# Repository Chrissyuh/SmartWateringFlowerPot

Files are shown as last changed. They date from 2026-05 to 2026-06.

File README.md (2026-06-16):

# Self-Watering Flower Pot V2

Custom ESP32-S3 controller hardware and bring-up firmware for a self-watering flower pot prototype.

This repository contains the KiCad design files, generated fabrication outputs, mechanical STEP exports, board renders, BOM notes, bring-up reports, and the first safe test firmware used on the assembled Board A prototype.

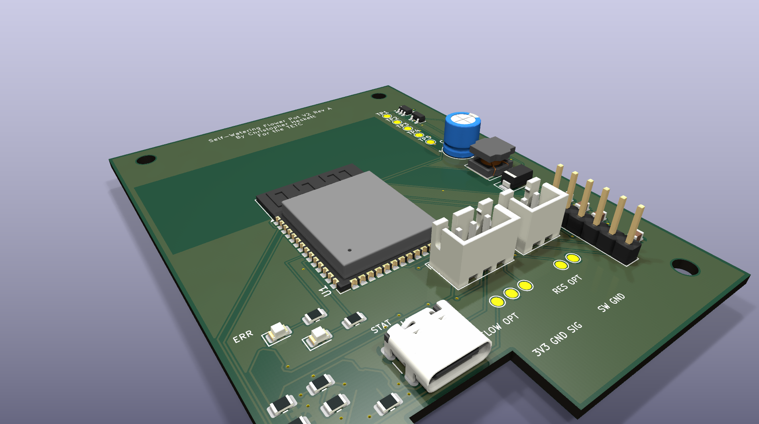
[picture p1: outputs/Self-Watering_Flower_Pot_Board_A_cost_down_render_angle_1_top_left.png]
Board A render


## Current Status

- Board A cost-down prototype has been fabricated and hand assembled for bring-up.
- USB-C power, 3.3 V regulator, ESP32-S3 native USB flashing, status LEDs, moisture ADC, and pump-gate bring-up checks have been tested.
- Current firmware is a supervised pump-test build with adjustable manual pump pulses and a hard 2 second firmware maximum.
- Board B UI daughterboard files remain in the repository as a deferred optional design.
- The cost-down Board A fabrication package is available in `fabrication/board_a_cost_down/`.

## Hardware Overview

Board A is the main controller board:

- ESP32-S3-WROOM-1-N8 module
- USB-C 5 V input
- AP63203 buck regulator for the 3.3 V logic rail
- Capacitive soil moisture sensor input on `J3`
- AO3400A low-side pump MOSFET footprint with gate resistor and pulldown
- SS34-style pump flyback diode
- Red error LED and green status LED
- Optional reservoir switch and flow pulse pads
- Debug/programming backup header `J7`
- Test points for rails and key signals

Board B is a deferred UI daughterboard concept with OLED/encoder support.

## Firmware

The current bring-up firmware lives in `firmware/testcode1/`.

It hosts a local Wi-Fi access point and web page:

- SSID: `FlowerPot-testcode1`
- Password: `flowerpot1`
- URL: `http://192.168.4.1`

The page shows moisture ADC readings, rolling average, min/max/span, rough wetness band, collapsible charts, deep ESP diagnostics, optional input short status, flow pulse count, AP-client/session counters, Wi-Fi settings, LED test buttons, session JSON export, diagnostics JSON export, and a supervised adjustable pump test button. The firmware also prints USB serial UI hints so the Windows helper in `firmware/testcode1/tools/` can open the best available UI URL from a data-cable connection.

Important safety rule: this is not autonomous watering firmware. The pump button requires a browser warning acknowledgement, and the firmware caps each pump run at 2000 ms.

## Repository Map

- `SmartWateringFlowerPot.kicad_pro`, `.kicad_sch`, `.kicad_pcb` - Board A KiCad project
- `board_b_ui/` - deferred UI board KiCad project
- `firmware/testcode1/` - PlatformIO bring-up firmware
- `docs/` - design notes, pinout, BOM notes, bring-up checklist, and hardening review
- `reports/` - saved ERC/DRC and audit reports
- `outputs/` - schematic PDFs, routing PDFs/SVGs, reference images, and 3D renders
- `fabrication/` - Gerbers, drill files, BOM CSVs, and fab zips
- `mechanical/` - STEP exports for enclosure/mechanical fit checks
- `CODEX_HANDOVER.md` - detailed project history and design context

## Bring-Up Notes

Before connecting a pump:

- Verify `+5V`, `+3V3`, and `GND`.
- Confirm there are no rail shorts.
- Confirm the ESP32 flashes over USB.
- Confirm `PUMP_GATE` remains LOW during boot/reset.
- Test the MOSFET gate with the pump disconnected.
- Use short, supervised pump tests only after the MOSFET and flyback diode are verified. Do not run the pump from a laptop USB port.

The moisture connector `J3` board order is:

```text
3V3  GND  SIG
```

The common capacitive sensor mapping is:

```text
VCC -> +3V3
GND -> GND
AOUT -> SIG
```

## Build Firmware

From `firmware/testcode1/`:

```powershell
python -m platformio run
python -m platformio run --target upload
```

The current `platformio.ini` targets the ESP32-S3 over `COM3`; change the port if your machine enumerates it differently.

## KiCad Checks

KiCad 9 is expected. If `kicad-cli` is on your PATH:

```powershell
kicad-cli sch erc --format report --output reports/erc.txt SmartWateringFlowerPot.kicad_sch
kicad-cli pcb drc --format report --output reports/drc.txt SmartWateringFlowerPot.kicad_pcb
```

KiCad GUI remains the source of truth for visual PCB edits.

## License

This project is released under the MIT License. See `LICENSE`.

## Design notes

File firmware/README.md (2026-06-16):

# Firmware

Firmware for the self-watering flower pot controller.

## Current Firmware

The active bring-up firmware is `testcode1/`.

It is a controlled pump-test build:

- Starts `GPIO4 / PUMP_GATE` LOW at boot.
- Allows a web UI pump pulse only after a first-use browser warning.
- Caps pump runtime in firmware at `2000 ms`.
- Hosts a local AP at all times.
- Can optionally join home Wi-Fi from the settings form while keeping the AP online.
- Prints USB serial UI hints so a Windows helper can open the web UI from a data-cable connection.
- Reads the moisture ADC continuously.
- Tracks moisture raw, rolling average, min/max/span, and rough diagnostic band.
- Records a rolling moisture/client history buffer and exposes collapsible charts in the hosted page.
- Downloads a session JSON export with firmware identity, moisture stats/history, AP-client counters, LED-test counters, flow pulses, and pump-run count.
- Exposes a deep diagnostics panel/API for reset reasons, boot count, pump-interrupted reset clues, heap/flash/sketch state, chip temperature, GPIO state, and loop health.
- Shows live optional input short status for `TP6-TP7` and `TP10-TP9`.
- Provides LED test buttons for the red and green board LEDs.

## Build

From `firmware/testcode1/`:

```powershell
python -m platformio run
python -m platformio run --target upload
```

The current configuration uses `COM3`; update `platformio.ini` if the ESP32-S3 appears on another port.

To open the UI from Windows over the USB serial discovery path:

```powershell
cd firmware\testcode1
.\tools\open-flowerpot-ui.ps1
```

For a simple plug-in watcher:

```powershell
cd firmware\testcode1
.\tools\watch-flowerpot-ui.ps1
```

This does not turn USB into Ethernet and does not switch Wi-Fi networks. It opens the ESP32's home-Wi-Fi URL when available, otherwise the AP URL.

## Pump Safety Direction

The current firmware is still only for supervised testing. Future autonomous pump firmware should add watering control only after hardware bring-up proves:

- MOSFET orientation is correct.
- `PUMP_GATE` is LOW during boot/reset.
- Flyback diode orientation is correct.
- Pump current is measured.
- A hard maximum runtime is enforced.
- Manual pump tests are short and explicit.

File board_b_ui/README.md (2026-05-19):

# Board B UI Daughterboard

Board B connects to Board A J6 through J1 with the same pin order:

1. `+3V3`
2. `GND`
3. `SDA`
4. `SCL`
5. `ENC_A`
6. `ENC_B`
7. `ENC_SW`
8. `ERROR_LED`
9. `STATUS_LED`

The OLED header target is the common 4-pin SSD1306 I2C module order `GND`, `VCC/3V3`, `SCL`, `SDA`. Verify the actual module pin order before fabrication.

The PCB outline is 64 mm x 38 mm with M2.5 non-plated mounting holes. The front side is the user-facing panel with the OLED header/module outline, EC11 encoder footprint, error/status LEDs, and labels. The 9-pin JST-XH cable connector and the support R/C parts are on the back side.

Board B has explicit routed copper for every net plus front/back `GND` zones. Refill zones in KiCad with `B` after manual edits and rerun DRC before fabrication.

Current review/fabrication artifacts:

- Checks: `reports/erc-board-b-front-panel.txt`, `reports/drc-board-b-front-panel.txt`, and `reports/drc-board-b-front-panel-parity.txt`
- Routing review: `outputs/BoardB_UI_routing.svg` and `outputs/BoardB_UI_routing.pdf`
- Schematic PDF: `outputs/BoardB_UI_schematic.pdf`
- STEP: `mechanical/BoardB_UI.step`
- Gerbers and drills: `../fabrication/board_b/`

The KiCad footprint references an EC11 3D model under `Rotary_Encoder.3dshapes`. This KiCad install does not include that model, so the STEP export may omit the encoder body even though the footprint, holes, and courtyard are present.

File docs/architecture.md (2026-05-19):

# Self-Watering Flower Pot V2 Architecture

## Rev A Goal

Rev A is a reliable embedded/mechatronics prototype for a self-watering flower pot. It uses an ESP32-S3 module, a custom PCB, clean connectorized wiring, a protected low-side pump driver, calibrated moisture sensing, a local OLED/encoder UI, and clear fault signaling.

The first build uses a hybrid workflow: Codex prepares documentation, checks, reports, and exports; KiCad GUI remains the source of truth for schematic placement, PCB placement, routing, board outline, and enclosure-sensitive mechanical decisions.

## Power Tree

```text
5V USB-C input
  |
  +-- Pump + bulk input capacitance
  |
  +-- AP63203WU-7 buck regulator
        |
        +-- +3V3 logic rail
              +-- ESP32-S3-WROOM-1-N8
              +-- Moisture sensor power/reference
              +-- OLED / UI logic
              +-- Pullups, LEDs, sensor inputs
```

Design rules:
- USB-C is a 5V sink only for Rev A; do not add USB-PD complexity.
- Add USB-C CC resistors if using a bare USB-C receptacle.
- Keep the buck regulator layout compact and close to its input/output capacitors and inductor.
- Keep pump current loops short and away from moisture ADC routing.
- Include test pads for `+5V`, `+3V3`, and `GND`.

## Functional Blocks

### MCU

Use `ESP32-S3-WROOM-1-N8` as the main controller. Place the module with the antenna at a board edge and respect the keepout. Preserve native USB if practical and include backup UART/debug pads.

### Pump Driver

Use a low-side N-MOSFET switch:

```text
+5V -> PUMP+ connector
PUMP- connector -> MOSFET drain
MOSFET source -> GND
ESP32 GPIO -> gate resistor -> MOSFET gate
MOSFET gate -> pulldown -> GND
Flyback diode across pump, reverse-biased during normal operation
```

Required support:
- AO3400A or equivalent logic-level N-MOSFET.
- 100 ohm to 330 ohm gate resistor.
- 100k gate pulldown.
- SS34 or similar flyback diode.
- Pump connector polarity labels.
- Test pad for `PUMP_GATE`.

### Sensors

The capacitive moisture sensor uses a 3-pin connector: `+3V3`, `GND`, `MOISTURE_ADC`. The ADC signal should use an ESP32-S3 ADC1-capable GPIO and may include a small RC low-pass filter plus a series resistor.

The reservoir switch is included as a 2-pin connector with a pullup or pulldown chosen during schematic capture. Firmware must treat an empty or missing reservoir as a pump lockout.

The flow sensor connector is optional-ready. If populated, `FLOW_PULSE` must be 3.3V-safe before reaching the ESP32.

### User Interface

The UI consists of an SSD1306 I2C OLED, EC11 rotary encoder with push switch, and red error LED. It may live on the main board or a cabled/daughter UI board depending on enclosure fit.

Use I2C pullups to `+3V3`, not `+5V`.

## First-Version KiCad Workflow

1. Build project structure and documentation.
2. Plan schematic sheets, connector pinouts, and ESP32 pins.
3. Place schematic manually in KiCad GUI.
4. Run ERC and save the report in `reports`.
5. Assign and verify footprints.
6. Place PCB manually in KiCad GUI with power, antenna, connector, and enclosure constraints first.
7. Route PCB manually in KiCad GUI.
8. Run DRC and save the report in `reports`.
9. Export fabrication outputs only after ERC/DRC results are acceptable.

## Open Mechanical Decisions

- Main board only vs. main board plus UI daughterboard.
- USB-C location relative to enclosure wall.
- OLED and encoder front-panel location.
- Mounting hole positions and screw/inset hardware.
- Pump and sensor connector access direction.

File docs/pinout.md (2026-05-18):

# ESP32-S3 Pin Allocation Draft

This is a Rev-A planning table for `ESP32-S3-WROOM-1-N8`. Confirm every selected pin against the exact module datasheet, KiCad symbol, and boot-strapping notes before routing.

Avoid using ESP32 pins that conflict with boot mode, flash/PSRAM, native USB, or module-reserved functions unless the schematic intentionally handles those constraints.

## Draft GPIO Allocation

| Signal | Draft GPIO | Direction | Electrical notes | Firmware notes |
|---|---:|---|---|---|
| `MOISTURE_ADC` | GPIO1 | Input analog | ADC1-capable, 3.3V max, optional RC filter | Average/filter and calibrate dry/wet values |
| `PUMP_GATE` | GPIO4 | Output | Gate resistor plus 100k pulldown required | Default LOW at boot; enforce max runtime |
| `I2C_SDA` | GPIO8 | I/O | Pull up to `+3V3` only | OLED and optional I2C devices |
| `I2C_SCL` | GPIO9 | Output | Pull up to `+3V3` only | OLED and optional I2C devices |
| `ENC_A` | GPIO10 | Input | Pullup and/or debounce | Rotary encoder channel A |
| `ENC_B` | GPIO11 | Input | Pullup and/or debounce | Rotary encoder channel B |
| `ENC_SW` | GPIO12 | Input | Pullup and debounce | Encoder push button |
| `RESERVOIR_SW` | GPIO13 | Input | Pullup/pulldown per switch wiring | Block pump when reservoir is empty |
| `FLOW_PULSE` | GPIO14 | Input | Must be 3.3V-safe; level shift if sensor is 5V | Interrupt-capable pulse count |
| `ERROR_LED` | GPIO15 | Output | LED resistor to suit chosen wiring | Active fault indication |
| `STATUS_LED` | GPIO16 | Output | Optional LED resistor | Heartbeat/status indication |
| `UART_TXD` | GPIO17 | Output | Test pad/header optional | Backup debug/programming |
| `UART_RXD` | GPIO18 | Input | Test pad/header optional | Backup debug/programming |

## Reserved / Special Signals

| Signal | Notes |
|---|---|
| `USB_D+` / `USB_D-` | Preserve native USB pins if used for programming/debug. Route as a controlled, short differential pair when practical. |
| `EN` | Include reset circuit and test pad. |
| `BOOT` / `IO0` | Include boot button or accessible test pad if needed by final programming flow. |
| `+3V3` | Logic rail for ESP32, OLED logic, pullups, and sensors that are 3.3V compatible. |
| `+5V` | Pump rail and USB input rail. Do not feed directly into ESP32 GPIO. |

## Connector Pinout Drafts

### J1 USB-C Power Input

| Pin group | Net |
|---|---|
| VBUS | `+5V` |
| GND | `GND` |
| CC1/CC2 | Sink resistors per USB-C receptacle design |
| D+/D- | Native USB if used; otherwise document no-connect intentionally |

### J2 Pump

| Pin | Net | Notes |
|---:|---|---|
| 1 | `PUMP_PLUS` / `+5V` | Label `PUMP+` |
| 2 | `PUMP_LOW` | To MOSFET drain; label `PUMP-` |

### J3 Moisture Sensor

| Pin | Net | Notes |
|---:|---|---|
| 1 | `+3V3` | Sensor power if sensor is 3.3V compatible |
| 2 | `GND` | Sensor ground |
| 3 | `MOISTURE_ADC` | ADC1 input, 3.3V max |

### J4 Reservoir Switch

| Pin | Net | Notes |
|---:|---|---|
| 1 | `RESERVOIR_SW` | Pullup or pulldown in schematic |
| 2 | `GND` or `+3V3` | Choose to match switch wiring |

Default: wire switch to `GND` and use a pullup to `+3V3`, unless the selected float switch requires otherwise.

### J5 Optional Flow Sensor

| Pin | Net | Notes |
|---:|---|---|
| 1 | `+3V3` or `+5V` | Match selected sensor |
| 2 | `GND` | Sensor ground |
| 3 | `FLOW_PULSE` | Must be level-shifted or divided if sensor output is 5V |

### J6 UI Connector

| Pin | Net | Notes |
|---:|---|---|
| 1 | `+3V3` | UI logic power |
| 2 | `GND` | UI ground |
| 3 | `I2C_SDA` | OLED data |
| 4 | `I2C_SCL` | OLED clock |
| 5 | `ENC_A` | Encoder A |
| 6 | `ENC_B` | Encoder B |
| 7 | `ENC_SW` | Encoder push |
| 8 | `ERROR_LED` | Front-panel fault LED |
| 9 | `STATUS_LED` | Optional status LED or spare GPIO |

## Must-Verify Before Routing

- Confirm the exact ESP32-S3 symbol pin numbers and module-reserved pins.
- Confirm `PUMP_GATE` does not toggle or float high during reset/boot.
- Confirm moisture ADC uses ADC1, not ADC2.
- Confirm I2C pullups are to `+3V3`.
- Confirm all external inputs are 3.3V-safe.
- Confirm every connector pin order matches the real cable/module orientation.

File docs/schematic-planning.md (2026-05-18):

# Schematic Planning Checklist

Do not begin PCB routing until this checklist is reviewed against the schematic.

## Suggested Sheets Or Sections

1. `Power_Input_Regulation`
2. `MCU_ESP32`
3. `Pump_Driver`
4. `Sensors_Connectors`
5. `User_Interface`
6. `Debug_Testpoints`

For a small first schematic, these may be sections on one sheet instead of separate hierarchical sheets.

## Support Components By Block

### Power Input And Regulation

- USB-C 5V input.
- CC resistors for USB-C sink behavior.
- Optional fuse/polyfuse.
- Bulk capacitance near pump/input.
- AP63203WU-7 buck regulator circuit from datasheet.
- `+5V`, `+3V3`, and `GND` test pads.

### ESP32-S3

- ESP32-S3-WROOM-1-N8 module.
- EN/reset circuit.
- BOOT/IO0 access if required.
- Native USB D+/D- if used.
- UART TX/RX test pads or header.
- Decoupling per module guidance.
- Antenna keepout note.

### Pump Driver

- Pump JST connector.
- AO3400A low-side MOSFET.
- Gate resistor.
- 100k gate pulldown.
- SS34 flyback diode.
- `PUMP_GATE` test pad.
- Clear polarity labels.

### Sensors

- Moisture sensor connector with `+3V3`, `GND`, `MOISTURE_ADC`.
- ADC series resistor and optional RC filter.
- Reservoir switch connector with defined pullup/pulldown.
- Optional flow connector with level shifting if pulse output is 5V.

### User Interface

- OLED I2C header or connector.
- I2C pullups to `+3V3`.
- EC11 encoder.
- Encoder push input.
- Red error LED and resistor.
- Optional status LED.
- UI connector if using a daughterboard.

## ERC Risks To Watch

- Missing power input source flags on `+5V` or `+3V3`.
- Hidden unconnected pins on connectors or modules.
- GPIO connected to 5V signals.
- I2C pullups tied to `+5V`.
- Missing gate pulldown on pump MOSFET.
- Flyback diode reversed or connected to wrong nets.
- Moisture signal on non-ADC or ADC2-only pin.
- Power pins hidden by symbol behavior.
- Ambiguous connector pin order.

## Manual KiCad GUI Placement Order

1. Place power input and regulator first.
2. Place ESP32 module and support parts.
3. Place pump driver and pump connector.
4. Place moisture, reservoir, and optional flow connectors.
5. Place OLED/encoder/UI connector.
6. Place LEDs and test points.
7. Assign footprints and verify every real-world connector footprint.
8. Run ERC before moving to PCB layout.

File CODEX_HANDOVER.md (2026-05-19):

# Self-Watering Flower Pot V2 — Codex + KiCad Handover

## Purpose of this file

This file is the main handover document for Codex while working inside the KiCad project folder for the Self-Watering Flower Pot V2.

Codex should treat this as project context, design intent, safety rules, and a task guide. KiCad GUI remains the source of truth for visual schematic/PCB work. Codex should mostly help with organization, checking, documentation, reports, symbol/footprint sanity review, small controlled edits, scripts, and manufacturing-output automation.

This project is not just a quick prototype. The goal is a product-ish engineering prototype: a custom PCB, clean wiring, serviceable enclosure, calibrated control logic, clear failure modes, and a design that could be explained to mentors, judges, or engineers.

---

## Project summary

Project name: **Self-Watering Flower Pot V2**

Core idea: An ESP32-based plant pot controller that reads a capacitive soil moisture sensor, decides when watering is needed, runs a small 5V pump through a MOSFET driver, optionally verifies water flow, displays status on a small OLED, and lets the user adjust/calibrate settings through a rotary encoder/button UI.

Primary goals:

- Create a custom KiCad PCB instead of a breadboard prototype.
- Make the wiring clean using JST connectors.
- Use a safe low-voltage pump driver with flyback protection.
- Separate noisy motor power from sensitive analog sensor readings as much as practical.
- Support calibration and reliable watering behavior in firmware.
- Design around a 3D-printed or fabricated enclosure in SolidWorks.
- Keep the design realistic for a novice KiCad user while still being serious and well-engineered.

Current status:

- Board A main-controller schematic and PCB are complete enough for manufacturer preview.
- Board B UI daughterboard schematic and PCB are complete enough for manufacturer preview.
- Both boards have current clean ERC, DRC, and schematic-parity reports.
- Fabrication packages, STEP exports, schematic PDFs, routing review outputs, and 3D review images have been generated.
- `docs/pre-order-hardening-review.md` documents the remaining real-world prototype tradeoffs: Rev A has no USB input fuse/current limiter, no USB data ESD array, and no extra local ESP32 bulk capacitor directly beside U1.
- The next major job is not more routing. It is final Gerber preview, final live BOM refresh, explicit acceptance of the Rev A protection tradeoff, and then careful bring-up after boards arrive.

---

## Overall architecture

High-level block diagram:

```text
USB-C 5V input
   |
   +--> 5V rail for pump / maybe external modules
   |
   +--> 3.3V buck regulator
            |
            +--> ESP32-S3 module
            +--> soil moisture sensor logic/reference, if sensor output is 3.3V-safe
            +--> OLED / encoder / LEDs / optional sensor logic

ESP32 ADC1 pin <--- capacitive soil moisture sensor analog output
ESP32 GPIO  ----> MOSFET gate ---> pump low-side switch
ESP32 I2C   ----> OLED display / optional I2C expansion
ESP32 GPIO  <---- rotary encoder A/B + push button
ESP32 GPIO  <---- reservoir float switch or low-water sensor
ESP32 GPIO  <---- optional flow sensor pulse output
ESP32 GPIO  ----> red error LED / status LEDs
```

Preferred Rev-A architecture:

- 5V USB-C input.
- 3.3V buck regulator for ESP32 and logic.
- ESP32-S3-WROOM-1-N8 module.
- 5V mini submersible pump or similar small DC pump.
- Low-side N-MOSFET pump driver.
- Flyback diode across pump.
- Capacitive soil moisture sensor through connector.
- 0.96 inch SSD1306 I2C OLED on a separate UI board or cable.
- EC11-style rotary encoder with push button.
- Red error LED.
- JST-XH connectors where practical.
- 0805 passives.
- Test pads and labeled connectors.

---

## Design philosophy

This should feel like a serious embedded/mechatronics product prototype, not a toy breadboard circuit.

Important priorities:

1. **Safety and robustness first**
   - Pump must not be able to run forever in normal firmware failure cases.
   - MOSFET gate needs a pulldown.
   - Pump needs flyback protection.
   - Inputs need to be 3.3V-safe for ESP32 pins.
   - Moisture readings should not be destroyed by motor noise.

2. **Serviceability**
   - Use connectors for pump, sensor, UI, reservoir sensor, and power where practical.
   - Label connectors clearly on silkscreen.
   - Include test pads for rails and key signals.
   - Make it possible to debug without guessing.

3. **Good learning workflow**
   - This is a novice KiCad project, so reminders and checklists matter.
   - Do not assume the schematic or PCB is correct because it “looks okay.”
   - Use ERC/DRC often.
   - Keep footprints, pinouts, connectors, and power rails explicit.

4. **SolidWorks integration**
   - PCB shape, connector placement, button/display locations, and mounting holes should eventually line up with the enclosure.
   - The expected workflow is:

```text
KiCad schematic + rough footprints
-> KiCad PCB rough placement
-> SolidWorks enclosure / fit check
-> KiCad PCB revision
-> SolidWorks revision
-> repeat
```

---

## Hard constraints / do-not-break rules

Codex must follow these rules unless the user explicitly says otherwise.

### KiCad file safety

- Do not blindly rewrite `.kicad_sch` or `.kicad_pcb` files.
- Before editing schematic or PCB files, explain the intended change.
- Prefer checklists, reports, Python scripts, and small controlled patches over huge direct edits.
- KiCad GUI remains the source of truth for visual PCB edits.
- Do not change footprints, net names, connector pinouts, power paths, board shape, or mounting constraints without explicit approval.
- Run ERC after schematic edits when possible.
- Run DRC after PCB edits when possible.
- Keep reports in `/reports`.
- Keep outputs in `/outputs` or `/fabrication`.

### Electronics safety

- ESP32 GPIOs are 3.3V logic. Do not feed 5V into ESP32 pins.
- Moisture sensor must use ADC1 pins when possible because ESP32 ADC2 conflicts with Wi-Fi on many ESP32 variants.
- Pump must be switched with a proper MOSFET driver, not directly from a GPIO.
- MOSFET gate must have a pulldown resistor.
- Pump must have a flyback diode or equivalent protection.
- Keep motor current path short and away from sensitive analog input traces.
- Add bulk capacitance near pump/5V input and local decoupling near ICs/modules.
- Use enough trace width for pump current.
- Include test points for 5V, 3.3V, GND, pump gate, moisture ADC, and I2C if space allows.

### Firmware behavior constraints that influence hardware

The hardware should support firmware safety features:

- Hysteresis around moisture threshold.
- Cooldown after watering.
- Maximum pump runtime or maximum mL per watering event.
- Pump lockout/fault if no water is detected.
- Optional flow pulse counting using interrupt-capable GPIO.
- Calibration stored in nonvolatile memory.
- User-visible fault state through OLED and red error LED.

---

## Preferred components / Rev-A defaults

These are the current preferred defaults, not final purchasing guarantees. Codex should use these as working assumptions unless the user provides updated part numbers.

| Function | Preferred part / style | Notes |
|---|---|---|
| MCU | ESP32-S3-WROOM-1-N8 | Module preferred over dev board for product-ish PCB. Native USB possible. |
| Main input | USB-C 5V | Use as power input. Rev-A can avoid USB-PD complexity. |
| 3.3V regulator | AP63203WU-7 buck | 5V to 3.3V logic rail. Check exact footprint and recommended layout. |
| Pump switch | AO3400A N-MOSFET | Low-side switching for small DC pump. Confirm current/thermal margin. |
| Flyback diode | SS34 or similar Schottky | Across pump/load path. Orientation matters. |
| Pump | Small 5V DC mini submersible pump | Exact pump may vary. Connector should allow replacement. |
| Soil sensor | Capacitive soil moisture sensor | Analog output. Must be 3.3V-safe before ESP32 ADC. |
| Display | 0.96 inch SSD1306 I2C OLED | Could be on UI daughterboard or cabled. |
| Encoder | EC11 rotary encoder w/ push | Main local UI control. Needs debouncing in firmware or hardware. |
| Error LED | Red LED | User-visible fault indicator. |
| Connectors | JST-XH preferred | Good for pump/sensors/power/internal wiring. |
| Passives | 0805 | Easier hand soldering than smaller packages. |
| Programming/debug | Native USB + UART header/test pads | Keep recovery/debug options. |

Potential optional components:

- Reservoir float switch connector.
- Flow sensor connector.
- Extra status LED.
- Buzzer footprint, only if useful.
- Expansion header, only if not bloating the board.
- Power switch footprint.

Avoid adding random features unless they directly support watering reliability, calibration, debugging, or enclosure usability.

---

## Board / schematic organization

The design may be one physical breakaway panel or separate PCBs. The preferred concept is a main control board plus optional breakaway UI/daughterboard sections if it reduces wiring or improves enclosure fit.

### Option A — Single main PCB only

Simpler KiCad project.

Pros:

- Less board-to-board wiring.
- Easier first PCB.
- Fewer connector mistakes.

Cons:

- OLED/button placement may be awkward.
- Enclosure front panel alignment may be harder.
- The board shape may become constrained by UI placement.

### Option B — Main board + UI daughterboard

Preferred if enclosure fit needs a front-facing display/control panel.

Main board contains:

- USB-C power input.
- 3.3V buck regulator.
- ESP32-S3 module.
- Pump MOSFET driver.
- Sensor connectors.
- Reservoir/flow connectors.
- Programming/debug headers or test pads.
- Main power/status LEDs.

UI board contains:

- OLED footprint/header.
- Rotary encoder.
- User button if separate from encoder push.
- Red error LED if front-facing.
- Board-to-board or cable connector back to main board.

Potential UI board connector signals:

```text
3V3
GND
SDA
SCL
ENC_A
ENC_B
ENC_SW
ERROR_LED or STATUS_LED
optional spare GPIO
```

### Option C — Main board + UI board + sensor/environment board

Only use if there is a real mechanical reason. More boards means more complexity, more connector pinouts, and more chances for mistakes.

---

## Suggested schematic sheets

A clean schematic structure matters. Suggested sheets:

1. `Power_Input_Regulation`
2. `MCU_ESP32`
3. `Pump_Driver`
4. `Sensors_Connectors`
5. `User_Interface`
6. `Debug_Testpoints`

If the project stays small, these can also be sections on one schematic page. The important part is readability and intentional net naming.

---

## Schematic block details

### 1. Power input and regulation

Purpose:

- Accept 5V input through USB-C.
- Generate stable 3.3V rail for ESP32 and logic.
- Provide enough bulk capacitance for pump startup transients.

Likely footprints/items:

- USB-C receptacle, USB2/power-only style if possible.
- CC resistors for USB-C sink behavior if using bare USB-C connector.
- Input fuse/polyfuse optional but useful.
- Reverse-polarity protection optional depending on input style.
- AP63203WU-7 buck regulator and required inductor/capacitors/resistors.
- 5V test pad.
- 3.3V test pad.
- Power LED optional.
- Bulk electrolytic/tantalum/polymer capacitor near 5V pump/input.
- 0.1 uF decoupling capacitors near logic IC/module pins as needed.

KiCad reminders:

- Use the exact regulator datasheet recommended footprint and layout.
- Switching regulator layout matters: keep input cap, diode/switching node/inductor feedback loop compact per datasheet.
- Keep noisy switch node copper small.
- Use a ground pour, but do not assume the pour fixes bad placement.
- Label rails clearly: `+5V`, `+3V3`, `GND`.

### 2. ESP32-S3 module

Purpose:

- Main controller.
- Reads moisture sensor.
- Controls pump MOSFET.
- Drives OLED over I2C.
- Reads encoder/buttons/sensors.
- Handles calibration and fault logic.

Likely footprints/items:

- ESP32-S3-WROOM-1-N8 module footprint.
- EN/reset circuit.
- Boot/IO0 button or programming support if needed.
- Native USB D+/D- routing if used.
- UART header/test pads as backup.
- Decoupling capacitors.
- Keepout under antenna.
- Mounting/placement with antenna at board edge where possible.

Important pin planning:

- Moisture sensor should use ADC1-capable pin.
- Flow sensor, if used, should use interrupt-capable GPIO.
- I2C needs SDA/SCL pins with pullups to 3.3V.
- Pump gate control GPIO should be safe at boot and should not accidentally turn pump on during reset.
- Encoder pins should be convenient for firmware interrupt/polling.
- Avoid strapping pins for outputs that may affect boot behavior unless intentionally designed.

Codex task:

- Help create a pin allocation table before routing.
- Check that selected pins do not conflict with bootstrapping, USB, flash, or ADC limitations.

### 3. Pump driver

Purpose:

- Switch the 5V pump safely using ESP32 logic.
- Protect against inductive kick.
- Avoid accidental pump activation at boot.

Likely footprints/items:

- Pump JST-XH connector: `PUMP+`, `PUMP-`.
- AO3400A N-MOSFET or equivalent logic-level N-MOSFET.
- Gate resistor, maybe ~100 ohm to 330 ohm.
- Gate pulldown, likely ~100k to GND.
- Flyback diode across pump, such as SS34.
- Optional TVS or snubber if noise is bad.
- Optional pump status LED, only if useful.
- Pump current path with suitable trace width.

Expected electrical topology:

```text
+5V -> Pump+ connector pin
Pump- connector pin -> MOSFET drain
MOSFET source -> GND
ESP32 GPIO -> gate resistor -> MOSFET gate
MOSFET gate -> pulldown -> GND
Flyback diode across pump, reverse-biased during normal operation
```

Safety reminders:

- The GPIO must not directly power the pump.
- The pump connector should be clearly labeled for polarity.
- The flyback diode orientation must be checked carefully.
- The MOSFET footprint pin order must be verified against the actual part and KiCad footprint.

### 4. Soil moisture sensor

Purpose:

- Read soil moisture through an analog voltage.
- Allow calibration in firmware.
- Keep analog signal reasonably clean.

Likely footprints/items:

- JST-XH or JST-PH connector for sensor.
- Pins likely: `3V3`, `GND`, `MOISTURE_ADC`.
- Optional RC low-pass filter on ADC input.
- Optional series resistor into ADC pin.
- Optional ESD protection if connector exits enclosure.
- Test pad for ADC signal.

Important constraints:

- Sensor output must not exceed 3.3V at ESP32 ADC.
- Use ADC1 pin where possible.
- Keep sensor trace away from pump trace and switching regulator noise.
- Firmware should average readings and use calibration, not raw magic numbers.

### 5. Reservoir sensor / float switch

Purpose:

- Detect low water or reservoir presence.
- Prevent pump from running dry.

Likely footprints/items:

- 2-pin JST connector.
- Pullup or pulldown resistor depending on switch wiring.
- Optional RC debounce.
- GPIO input.
- Silkscreen label showing expected switch behavior if known.

Firmware behavior:

- If reservoir empty or missing, block watering.
- Display fault message and turn on error LED.

### 6. Optional flow sensor

Purpose:

- Verify that water is actually moving.
- Count pulses to estimate amount of water dispensed.

Likely footprints/items:

- 3-pin connector: `5V or 3V3`, `GND`, `FLOW_PULSE`.
- Pullup to correct voltage.
- Level shifting if sensor output is 5V.
- Optional input protection.
- Interrupt-capable ESP32 GPIO.

Constraints:

- Do not connect a 5V pulse output directly to ESP32 GPIO.
- Flow counting should be interrupt-based in firmware.
- If no pulses arrive after pump starts, enter no-flow fault.

### 7. User interface

Purpose:

- Show moisture/status/faults/settings.
- Let user calibrate dry/wet values and adjust thresholds.

Likely footprints/items:

- 0.96 inch SSD1306 I2C OLED header or direct-solder footprint.
- EC11 rotary encoder.
- Encoder push button.
- Red error LED with resistor.
- Optional status LED.
- UI board connector if separate.

Signals:

```text
3V3
GND
SDA
SCL
ENC_A
ENC_B
ENC_SW
ERROR_LED
optional spare
```

Reminders:

- I2C pullups should go to 3.3V, not 5V.
- OLED module voltage compatibility must be checked.
- Encoder needs debouncing in firmware; small RC filters are optional.
- Error LED should be visible from outside the enclosure.

### 8. Debug/test points

Purpose:

- Make first bring-up less painful.
- Make it easier to diagnose board mistakes.

Recommended test points:

- `GND`
- `+5V`
- `+3V3`
- `EN`
- `BOOT/IO0` if relevant
- `TXD`
- `RXD`
- `USB_D+`
- `USB_D-`
- `PUMP_GATE`
- `MOISTURE_ADC`
- `SDA`
- `SCL`
- `FLOW_PULSE` if used

---

## Net naming conventions

Use clear net names. Examples:

Power:

```text
+5V
+3V3
GND
VBUS
```

Pump:

```text
PUMP_GATE
PUMP_LOW
PUMP_PLUS
```

Sensors:

```text
MOISTURE_ADC
RESERVOIR_SW
FLOW_PULSE
```

I2C:

```text
I2C_SDA
I2C_SCL
```

UI:

```text
ENC_A
ENC_B
ENC_SW
ERROR_LED
STATUS_LED
```

Do not use vague net names like `SIGNAL`, `SENSOR`, `OUT`, `GPIO1`, unless they are temporary and documented.

---

## Footprint checklist

Before routing, Codex should help the user verify this list.

### Power

- USB-C connector footprint matches actual part.
- CC resistors are included if using USB-C power input directly.
- Buck regulator footprint matches exact AP63203 package.
- Inductor footprint matches actual selected inductor.
- Input/output capacitors have correct package and voltage rating.
- Test points for 5V/3.3V/GND.

### MCU

- ESP32-S3-WROOM footprint exactly matches module variant.
- Antenna keepout is present and respected.
- EN/BOOT/programming circuit is correct.
- USB data pins, if used, are routed intentionally.
- UART backup header/test pads exist.

### Pump driver

- AO3400A footprint pinout checked against datasheet.
- SS34 diode footprint checked.
- Pump connector footprint matches actual JST part.
- Gate resistor/pulldown included.
- Pump current traces sized appropriately.

### Sensors

- Moisture sensor connector pinout documented.
- Reservoir switch connector documented.
- Flow sensor connector documented if included.
- ADC protection/filtering considered.
- 5V sensor outputs are level-shifted or divided if needed.

### UI

- OLED module footprint/header matches actual module pin order.
- Encoder footprint matches actual EC11 encoder variant.
- Button footprint matches actual part.
- LED polarity clear on silkscreen.
- UI connector pinout documented on both boards if separate.

### Mechanical

- Mounting holes sized and grounded or isolated intentionally.
- Connector access matches enclosure concept.
- USB-C port location matches enclosure access.
- OLED/encoder positions match front panel if using UI board.
- Board edge clearances are reasonable.

---

## KiCad novice reminders

Codex should remind the user of these at the right times, especially before committing to PCB layout.

### Schematic reminders

- Every symbol needs the correct footprint assigned before PCB layout.
- Power symbols create global nets; use them carefully.
- ERC warnings are not automatically false. Read them.
- Add PWR_FLAG only when the warning is about KiCad not understanding a rail is powered, not to hide real problems.
- Label connector pins clearly.
- Keep pin numbers and connector order consistent with real wiring.
- Make a pinout table before routing.
- Check OLED module pin order; cheap modules may differ.

### PCB reminders

- Set board outline on `Edge.Cuts`.
- Place mounting holes early.
- Place mechanical connectors early.
- Place the ESP32 antenna near board edge with keepout respected.
- Keep pump current loop short.
- Keep moisture ADC away from pump and switching regulator noise.
- Use a ground plane/pour.
- Refill zones before final DRC.
- Use thicker traces for pump/current paths.
- Use 45-degree routing unless there is a reason not to.
- Label connectors on silkscreen.
- Add version text like `Self-Watering Flower Pot V2 Rev A` on silkscreen.
- Export a 3D model and check in SolidWorks or KiCad 3D viewer.

### Manufacturing reminders

- Run DRC before ordering.
- Check drill files.
- Check Gerbers in a Gerber viewer.
- Verify board dimensions.
- Verify connector footprints with datasheets or printed 1:1 footprint check.
- Confirm minimum trace/space and hole sizes match the PCB manufacturer.
- Do not order before checking polarity marks and connector pinouts.

---

## Firmware behavior target

The PCB should support this kind of firmware flow:

```text
Boot
  -> initialize display, sensors, pump output off
  -> read calibration/settings from NVM
  -> show status

Main loop
  -> read moisture multiple times and average/filter
  -> compare against calibrated dry/wet thresholds
  -> check reservoir state
  -> if too dry and allowed by cooldown, water plant
  -> after watering, wait/cooldown and recheck
  -> handle errors visibly
```

Watering logic requirements:

- Use hysteresis so pump does not rapidly toggle.
- Use cooldown so watering is not repeated too quickly.
- Use maximum runtime or maximum mL limit.
- If flow sensor exists, count pulses using interrupt-based logic.
- If pump is on but no flow is detected after a short grace period, stop and show fault.
- Store calibration in nonvolatile memory.

UI target:

- Show current moisture value/percentage.
- Show dry/wet calibration state.
- Show pump status.
- Show reservoir/fault status.
- Allow calibration of dry and wet readings.
- Allow threshold adjustment.
- Allow manual pump test with safety timeout.

---

## Suggested project folder structure

```text
SelfWateringFlowerPotV2/
  SelfWateringFlowerPotV2.kicad_pro
  SelfWateringFlowerPotV2.kicad_sch
  SelfWateringFlowerPotV2.kicad_pcb
  CODEX_HANDOVER.md
  AGENTS.md
  /docs
    architecture.md
    pinout.md
    bringup-checklist.md
    bom-notes.md
  /reports
    erc.txt
    drc.txt
  /outputs
  /fabrication
    gerbers/
    drill/
    bom/
    pickplace/
  /mechanical
    board-export.step
    enclosure-notes.md
  /firmware
    README.md
```

If the KiCad project already has a different name, use that project name consistently.

---

## Recommended `AGENTS.md` content

Create or update an `AGENTS.md` file in the project root with this content:

```md
# KiCad Project Rules for Codex

This is a KiCad PCB project for the Self-Watering Flower Pot V2.

Rules:
- Do not blindly rewrite .kicad_sch or .kicad_pcb files.
- Before editing schematic or PCB files, explain the intended change first.
- Prefer using kicad-cli, Python scripts, reports, and small controlled edits.
- Run ERC after schematic changes when possible.
- Run DRC after PCB changes when possible.
- Put reports in /reports.
- Put generated manufacturing/export files in /fabrication or /outputs.
- Do not change footprints, net names, connector pinouts, power paths, board shape, mounting holes, or enclosure constraints unless explicitly asked.
- If a change is risky, create a script or patch instead of directly modifying the KiCad design file.
- KiCad GUI remains the source of truth for visual PCB edits.
- Treat CODEX_HANDOVER.md as the main project context file.
```

---

## First Codex prompt to use in the Codex app

Paste this into Codex while the KiCad project folder is open:

```text
Read CODEX_HANDOVER.md and AGENTS.md first.

This is a new KiCad project for the Self-Watering Flower Pot V2. Do not edit schematic or PCB files yet.

First tasks:
1. Identify the KiCad project files in this folder.
2. Check whether kicad-cli works.
3. Create /docs, /reports, /outputs, /fabrication, and /mechanical folders if they do not exist.
4. Create docs/pinout.md with a draft pin allocation table for ESP32-S3-WROOM-1-N8 based on the handover requirements.
5. Create docs/bringup-checklist.md with a first-power-on checklist.
6. Create docs/bom-notes.md with a draft BOM category list, not final part orders.
7. Do not modify .kicad_sch or .kicad_pcb yet.
8. Summarize what you created and what decisions still need user approval.
```

---

## Second Codex prompt: schematic planning

Use this after the first prompt succeeds:

```text
Using CODEX_HANDOVER.md, propose the schematic structure for this KiCad project.

Do not edit design files yet.

Give me:
1. Recommended schematic sheets or sections.
2. Exact connector list and pinout draft.
3. Power tree.
4. ESP32 pin allocation draft.
5. Required support components for each block.
6. ERC risks to watch for.
7. A checklist of what I should place manually in KiCad GUI first.

Keep the design realistic for Rev A and do not add feature creep.
```

---

## Third Codex prompt: after schematic parts are placed

Use this once the user has started placing parts in KiCad:

```text
Inspect the KiCad schematic. Do not edit it yet.

Check for:
1. Missing footprints.
2. Missing power symbols or unclear rails.
3. ESP32 pin conflicts or bad boot strap choices.
4. Missing pump gate pulldown, gate resistor, or flyback diode.
5. Sensor outputs that may not be 3.3V-safe.
6. Missing I2C pullups.
7. Missing test points.
8. Connector pinout ambiguity.
9. ERC issues.

Run ERC using kicad-cli if possible and save the report in /reports.
Then summarize fixes in priority order.
```

---

## Fourth Codex prompt: before PCB routing

Use this after schematic is mostly done and footprints assigned:

```text
Before I start PCB routing, review the schematic and footprint assignments.

Do not edit the PCB yet.

Create a placement strategy for:
1. USB-C input.
2. Buck regulator and power path.
3. ESP32 module and antenna keepout.
4. Pump connector and MOSFET loop.
5. Moisture sensor connector and ADC trace.
6. UI connector/OLED/encoder path.
7. Mounting holes and enclosure constraints.
8. Test points.

Also create a list of high-risk footprints I should print/check at 1:1 scale before ordering.
```

---

## Fifth Codex prompt: after PCB placement/routing

Use this after layout work:

```text
Inspect the PCB layout. Do not make direct edits yet.

Check for:
1. Board outline on Edge.Cuts.
2. Mounting holes.
3. ESP32 antenna keepout.
4. Pump current trace width and loop area.
5. Buck regulator layout risks.
6. Analog moisture trace noise risks.
7. Ground pour / zone fill issues.
8. Connector silkscreen labels.
9. Polarity markings.
10. Test point access.
11. DRC errors.

Run DRC using kicad-cli if possible and save the report in /reports.
Summarize manufacturing risks and exact fixes.
```

---

## Sixth Codex prompt: fabrication export

Use this only when schematic and PCB are reviewed:

```text
Prepare fabrication outputs for review.

Before exporting, run ERC and DRC and save reports.
If there are blocking errors, stop and summarize them instead of exporting.

If checks pass or only approved warnings remain:
1. Export Gerbers to /fabrication/gerbers.
2. Export drill files to /fabrication/drill.
3. Export BOM if possible to /fabrication/bom.
4. Export position file if useful to /fabrication/pickplace.
5. Export STEP model to /mechanical/board-export.step if possible.
6. Summarize exactly what files were created.
```

---

## Bring-up checklist draft

Use this after the PCB arrives, before connecting the pump.

### Before soldering

- Inspect board for visible fab defects.
- Confirm board revision text.
- Confirm USB-C footprint orientation.
- Confirm ESP32 module orientation.
- Confirm diode polarity markings.
- Confirm MOSFET orientation.
- Confirm connector labels and pin 1 markers.

### After partial soldering: power only

- Solder power input/regulator section first if possible.
- Do not install ESP32 module until 3.3V rail is verified, if assembly order allows.
- Apply 5V current-limited power.
- Check 5V rail.
- Check 3.3V rail.
- Check regulator temperature.
- Check for shorts between 5V/GND and 3.3V/GND.

### After MCU soldering

- Verify ESP32 power pins.
- Try programming or USB detection.
- Blink status/error LED.
- Confirm boot/reset behavior.

### Sensor/UI tests

- Test OLED I2C scan.
- Test encoder rotation and button.
- Read moisture ADC in air.
- Read moisture ADC with sensor in water/damp soil only if sensor supports it.
- Test reservoir switch input.
- Test flow sensor pulses if included.

### Pump test

- Test MOSFET gate output with pump disconnected.
- Connect dummy load or LED/resistor if useful.
- Connect pump with current-limited supply.
- Run very short pump pulse.
- Verify flyback diode orientation and MOSFET temperature.
- Verify pump cannot turn on during reset/boot.

---

## Open decisions to resolve

Codex should help track these decisions rather than assuming them.

1. Exact KiCad project name.
2. Exact USB-C connector part.
3. Exact pump part and current draw.
4. Exact moisture sensor module pin order and voltage behavior.
5. Whether flow sensor is included on Rev A or only connector-ready.
6. Whether reservoir float switch is included on Rev A.
7. Whether OLED is direct on main board, cabled, or on UI daughterboard.
8. Whether board is one PCB, breakaway panel, or separate boards.
9. Exact enclosure layout and mounting hole positions.
10. Exact PCB manufacturer constraints.
11. Whether native USB programming is enough or UART header is required.
12. Whether battery operation is completely out of scope for Rev A.

Current likely defaults:

- Use USB-C 5V, not battery.
- Include reservoir switch connector.
- Include flow sensor connector if not too much complexity, but design should still work without installing it.
- Use main board + possible UI daughterboard if enclosure fit benefits.
- Focus on a reliable Rev A, not maximum features.

---

## Rough pricing categories

This is not a final BOM. It is for planning.

| Category | Rough expected cost range | Notes |
|---|---:|---|
| PCB fabrication | $5–$30 | Depends on size, quantity, shipping, panels. |
| ESP32-S3 module | $3–$8 | Depends source and module variant. |
| Power parts | $3–$10 | USB-C, buck, inductor, caps, protection. |
| Pump driver parts | $1–$4 | MOSFET, diode, resistors, connector. |
| OLED | $2–$8 | Module style varies. |
| Encoder/buttons/LEDs | $1–$5 | Depends quality and quantity. |
| Sensors | $2–$15 | Moisture, float, optional flow. |
| Connectors/wires | $3–$15 | JST housings, crimps, premade leads. |
| Enclosure hardware | $2–$15 | Screws, inserts, gasket, printed parts. |
| Spare/debug parts | $5–$20 | Strongly recommended. |

Likely Rev-A total: about **$30–$100**, depending on parts already owned, shipping, and whether multiple boards are ordered.

---

## What Codex should produce as receipts

Good project artifacts:

- `docs/architecture.md`
- `docs/pinout.md`
- `docs/bringup-checklist.md`
- `docs/bom-notes.md`
- ERC and DRC reports.
- PCB screenshots or exported images.
- STEP model for enclosure fitting.
- Gerber/drill outputs when ready.
- A short engineering writeup explaining design choices and safety features.
- A test log after bring-up.

Avoid:

- Random generated files with unclear purpose.
- Large direct rewrites of KiCad files.
- Feature creep.
- Hiding ERC/DRC warnings without understanding them.

---

## Human design notes

The user is strong technically but new to KiCad, so Codex should act like a careful engineering assistant:

- Catch missing details early.
- Explain risks clearly.
- Use checklists.
- Keep changes controlled.
- Assume the user will make many final choices in KiCad GUI.
- Do not water down the project. The goal is a serious embedded/mechatronics prototype.

The ideal Codex behavior is not “finish the PCB for me.” The ideal behavior is:

```text
organize -> inspect -> warn -> generate checklists -> run checks -> explain errors -> help export -> document evidence
```

---

## Immediate next step

After this file is placed in the KiCad project root, create `AGENTS.md` using the recommended content above, then open the project folder in the Codex app and run the first Codex prompt.

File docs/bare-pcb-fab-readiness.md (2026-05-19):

# Bare-PCB Fab Readiness

Date: 2026-05-19

## Status

Board A and Board B are both fab-ready for bare PCB manufacturer preview.

Board A now passes ERC, DRC, and schematic parity with 0 violations and 0 unconnected pads after the four open connections were fixed and copper zones were refilled. Board B remains clean after the front-panel placement cleanup and refreshed fabrication export.

One-large-order readiness status is tracked in `docs/one-large-order-readiness.md`. The current purchasing BOM is `fabrication/bom/order-readiness-purchasing-bom.csv`; it still needs a live stock/price refresh before parts checkout.

## Board A Fab-Ready Outputs

Current reports:

- `reports/erc-order-batch-board-a.txt`: 0 violations.
- `reports/drc-order-batch-board-a.txt`: 0 violations, 0 unconnected pads.
- `reports/drc-order-batch-board-a-parity.txt`: 0 violations, 0 unconnected pads, 0 schematic parity issues.

Fixed routing/placement items:

- `R8` pad 1 to `Net-(J4-Pin_1)` reservoir switch signal.
- `C4` pad 1 to `Net-(TP5-Pin_1)` optional moisture ADC filter node.
- `R6` pad 2 to `Net-(J6-Pin_3)` SDA pullup branch.
- `U1` pad 18 to `J6` pin 5 / `Net-(J6-Pin_5)` encoder A.

Board A bare-board output package:

- Gerbers: `fabrication/board_a/gerbers/`
- Drill files and drill maps: `fabrication/board_a/drill/`
- Fab zip: `fabrication/board_a/Self-Watering_Flower_Pot_Board_A_fab.zip`
- STEP: `mechanical/BoardA.step`
- Schematic PDF: `outputs/BoardA_schematic_order_batch.pdf`
- Routing review SVG/PDF: `outputs/BoardA_routing_order_batch.svg`, `outputs/BoardA_routing_order_batch.pdf`
- 3D review images: `outputs/BoardA_3d_top.png`, `outputs/BoardA_3d_bottom.png`

## Board B Fab-Ready Outputs

Checks:

- `board_b_ui/reports/erc-board-b-front-panel.txt`: 0 violations.
- `board_b_ui/reports/drc-board-b-front-panel.txt`: 0 violations, 0 unconnected items.
- `board_b_ui/reports/drc-board-b-front-panel-parity.txt`: 0 violations, 0 unconnected items, 0 schematic parity issues.
- `board_b_ui/reports/erc-one-large-order-board-b.txt`: 0 ERC messages, 0 errors, 0 warnings.
- `board_b_ui/reports/drc-one-large-order-board-b.txt`: 0 DRC violations, 0 unconnected items.
- `board_b_ui/reports/drc-one-large-order-board-b-parity.txt`: 0 DRC violations, 0 unconnected items.
- `board_b_ui/reports/erc-order-batch-board-b.txt`: 0 violations.
- `board_b_ui/reports/drc-order-batch-board-b.txt`: 0 violations, 0 unconnected items.
- `board_b_ui/reports/drc-order-batch-board-b-parity.txt`: 0 violations, 0 unconnected items, 0 schematic parity issues.

Bare-board output package:

- Gerbers: `fabrication/board_b/gerbers/`
- Drill files and drill maps: `fabrication/board_b/drill/`
- STEP: `board_b_ui/mechanical/BoardB_UI.step`
- Schematic PDF: `board_b_ui/outputs/BoardB_UI_schematic.pdf`
- Routing review: `board_b_ui/outputs/BoardB_UI_routing.svg`
- Routing review PDF: `board_b_ui/outputs/BoardB_UI_routing.pdf`
- Fab zip: `fabrication/board_b/Self-Watering_UI_Board_B_fab.zip`
- 3D review images: `board_b_ui/outputs/BoardB_UI_3d_top.png`, `board_b_ui/outputs/BoardB_UI_3d_bottom.png`

Known acceptable Board B warning during STEP export:

- KiCad could not find the EC11 encoder 3D model. The footprint, pads, and holes are present; the STEP may omit the encoder body.

## Order Checklist

Before ordering both boards together:

- Upload both final Gerber zip files to the PCB manufacturer's previewer.
- Inspect board outline, holes, copper, solder mask, silkscreen, and pin-1 marks for both boards.
- Visually recheck Board A `J6` against Board B `J1`:
  `1=+3V3`, `2=GND`, `3=SDA`, `4=SCL`, `5=ENC_A`, `6=ENC_B`, `7=ENC_SW`, `8=ERROR_LED`, `9=STATUS_LED`.
- Confirm Board B back-side right-angle 9-pin JST cable direction in 3D view against the enclosure/front-panel plan.
- Confirm the physical OLED module pin order is `GND, VCC, SCL, SDA`.
- Refresh the purchasing BOM live before checking out parts.

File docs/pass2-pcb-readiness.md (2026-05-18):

# Pass 2 PCB Readiness

Pass 2 resolves the schematic-level blockers that prevented moving into PCB placement. The schematic is intended to be ready for `Update PCB from Schematic` after a visual review in KiCad GUI.

## Locked Rev-A Assumptions

- Main PCB uses a cabled UI connector. OLED, encoder, and front-panel LEDs are not placed directly on the main board in Rev A.
- USB-C is a 5V sink plus native USB2 data only. No USB-PD circuitry is included.
- Flow sensor support is optional-ready and defaults to a 3.3V-safe pulse signal.
- Moisture sensor is powered from `+3V3`; its analog output must stay within the ESP32 ADC input range.
- Pump is a 5V load switched by a low-side AO3400A MOSFET with a gate resistor, 100k pulldown, and SS34 flyback diode.

## Selected Footprints And Values

| Ref | Function | Pass 2 value / footprint | Notes |
|---|---|---|---|
| `J1` | USB-C input/native USB | `Connector_USB:USB_C_Receptacle_GCT_USB4105-xx-A_16P_TopMnt_Horizontal` | KiCad footprint pads match the USB-C USB2 symbol pad names. Confirm exact purchasable GCT USB4105 variant before ordering. |
| `U2` | 3.3V buck regulator | `AP63203WU-7`, `Package_TO_SOT_SMD:TSOT-23-6` | Fixed 3.3V AP63203 family part. Layout must follow datasheet. |
| `L1` | Buck inductor | `3.9uH shielded >=3A Isat`, `Inductor_SMD:L_Bourns_SRN6045TA` | Datasheet-aligned value for the AP63203 3.3V output; confirm final stocked part current, DCR, and height. |
| `C1` | Buck input capacitor | `10uF 10V X7R input`, `C_0805` | Place close to U2 VIN/GND. |
| `C2` | Buck output capacitor | `22uF 6.3V X7R output`, `C_0805` | Place close to inductor/output return path. |
| `C5` | Buck output capacitor | `22uF 6.3V X7R output`, `C_0805` | Second output capacitor added to match the AP63203 datasheet recommendation. |
| `C3` | Bootstrap capacitor | `100nF 10V BST`, `C_0805` | Keep loop short between BST and SW. |
| `C6` | Pump rail bulk capacitor | `100uF 10V pump bulk`, `CP_Radial_D6.3mm_P2.50mm` | Place near `J2` and observe polarity. |
| `R10` | Moisture ADC input resistor | `1k ADC series`, `R_0805` | Adds basic ADC input protection/isolation. |
| `C4` | Moisture ADC filter option | `100nF ADC filter DNP`, `C_0805` | Optional low-pass cap from ADC node to ground; leave DNP unless readings are noisy. |
| `TP1`-`TP5` | Bring-up test pads | `TestPoint_Pad_D1.5mm` | Nets are `+5V`, `GND`, `+3V3`, `PUMP_GATE`, and `MOISTURE_ADC`. |

## Connector Pinouts To Preserve

| Ref | Pin order |
|---|---|
| `J2` pump | `1=+5V`, `2=PUMP_LOW` switched by MOSFET |
| `J3` moisture | `1=+3V3`, `2=GND`, `3=MOISTURE_ADC` through `R10` |
| `J4` reservoir | `1=RESERVOIR_SW`, `2=GND`; switch closes to ground with `R8` pullup |
| `J5` flow optional | `1=+3V3`, `2=GND`, `3=FLOW_PULSE`; pulse must be 3.3V-safe |
| `J6` UI | `1=+3V3`, `2=GND`, `3=SDA`, `4=SCL`, `5=ENC_A`, `6=ENC_B`, `7=ENC_SW`, `8=ERROR_LED`, `9=STATUS_LED` |
| `J7` debug | `1=+3V3`, `2=GND`, `3=TXD0`, `4=RXD0`, `5=EN`, `6=IO0/BOOT` |

## PCB Placement Notes

- Place `J1` on a board edge before routing anything else.
- Place `U1` with antenna at a board edge and keep copper/mechanical interference out of the antenna area.
- Place `U2`, `C1`, `C2`, `C3`, `C5`, and `L1` as a tight buck-regulator cluster before routing other signals.
- Keep the pump current loop from `+5V -> J2 -> Q1 -> GND` short and away from `MOISTURE_ADC`.
- Place `C6` close to `J2` with a short return path into the main ground plane.
- Place `R10` and optional `C4` close to the ESP32 ADC pin side of the moisture signal.
- Route USB D+/D- intentionally as a short pair from `J1` to the ESP32 native USB pins.
- Put connector labels and pin-1 marks on silkscreen before first board order.

## Remaining Procurement Warnings

- Confirm the exact USB-C connector variant and print/check the footprint before ordering.
- Confirm the exact inductor part, height, saturation current, and availability.
- Confirm actual pump running and startup/stall current before choosing trace width.
- Confirm moisture sensor module pin order and analog output range.
- Confirm flow sensor voltage output before populating it.

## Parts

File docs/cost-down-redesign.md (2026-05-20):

# Cost-Down Board-A-Only Redesign

Date: 2026-05-19

This branch preserves `main` as the two-board OLED/encoder version and creates a cheaper first-build variant on `codex/cost-down-board-a-only`.

## Design Scope

- Required board: Board A main controller only.
- Deferred board: Board B UI daughterboard remains in the repo but is not part of this cost-down order.
- Removed required UI: OLED, EC11 encoder, UI cable connector, Board B PCB, UI cable housings, and UI passives.
- Required local UI: two Board A 0805 LEDs, active-high from ESP32 GPIO through 330 ohm resistor to LED to GND.
- Required sensing: moisture sensor connector remains.
- Optional sensing: reservoir switch and flow pulse are solder/test pads only and are disabled by firmware default.

## Board A Changes

- `J6`, `R6`, `R7`, and `R8` are excluded from the cost-down board population.
- `J4` and `J5` are excluded as required JST connectors; their useful nets are exposed as optional pads instead.
- Added `R11`/`D2` for `ERROR_LED`.
- Added `R12`/`D3` for `STATUS_LED`.
- Added optional pads:
  - `TP6`: `RESERVOIR_SW`
  - `TP7`: `GND`
  - `TP8`: `+3V3`
  - `TP9`: `GND`
  - `TP10`: `FLOW_PULSE`
- Board outline, mounting holes, USB-C, ESP32-S3, AP63203 buck, pump connector, moisture connector, debug header, and pump driver power path are unchanged.
- The Board A outline now includes a bottom-edge USB-C clearance notch so normal USB-C cable housings sit outside the PCB instead of colliding with the board.

## Firmware Defaults

- `RESERVOIR_SENSOR_ENABLED=false`
- `FLOW_SENSOR_ENABLED=false`
- Missing reservoir/flow hardware must not block watering unless explicitly enabled.
- USB-C native ESP32-S3 programming remains the primary upload path.
- `J7` remains the fallback 3.3 V UART/EN/BOOT recovery path.
- Calibration and configuration should use USB serial or compile-time constants for the first cheap version.
- The pump must still enforce a maximum runtime timeout and boot-safe gate behavior.

## Cost Target

`fabrication/bom/cost-down-5-sets.csv` estimates the required five-unit cost-down electronics batch at about `$90.77`, or `$18.15/unit`, before shipping, tax, tariffs, tools, enclosure material, and support accessories.

That estimate uses the cheaper generic capacitive moisture sensor line. If the DFRobot SEN0193 sensor is used instead, add about `$24.25` to the five-unit batch.

## Verification

- Board A ERC: `reports/erc-cost-down-board-a.txt`
- Board A DRC: `reports/drc-cost-down-board-a.txt`
- Board A schematic parity: `reports/drc-cost-down-board-a-parity.txt`

Current result after the redesign:

- ERC: 0 violations
- DRC: 0 violations
- Unconnected pads: 0
- Schematic parity issues: 0

## Ordering Notes

- Upload only `Self-Watering_Flower_Pot_Board_A_cost_down_fab.zip` for this version.
- Use the regenerated zip dated after the USB-C notch fix; older cost-down zips are superseded.
- Do not order Board B for this branch.
- Reservoir and flow parts are not required for the first cheap build.
- Before checkout, refresh live supplier pricing and verify the generic moisture sensor pin order and output range.

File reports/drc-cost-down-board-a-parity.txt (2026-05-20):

** Drc report for SmartWateringFlowerPot.kicad_pcb **
** Created on 2026-05-19T23:21:10-0500 **

** Found 0 DRC violations **

** Found 0 unconnected pads **

** Found 0 Footprint errors **

** End of Report **

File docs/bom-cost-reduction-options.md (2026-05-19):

# BOM Cost Reduction Options

Date checked: 2026-05-19

Baseline: `docs/total-bom-5-sets.md` estimates a 5-system minimum-buy order at $275.10 before shipping, tax, tariffs, tools, and enclosure material.

This file lists cost reductions found in a live supplier search. Do not apply the risky substitutions directly to the purchasing BOM until the part is physically/electrically verified.

## Best Savings

| Change | Current line | Lower-cost option found | Estimated savings | Risk |
|---|---:|---:|---:|---|
| Buy lower-cost 5 V / 2 A adapters | $50.00 | xUmp 5 V / 2 A adapters at $3.59 each, 5 = $17.95 | $32.05 | Medium: mains adapter quality/safety matters. Prefer certified adapters or known-good adapters already on hand. |
| Use generic capacitive soil sensors | $28.50 | AliExpress-listed V1.2 sensor at about $0.85 each, 5 = $4.25 | $24.25 | High: generic V1.2 sensors vary; confirm 3.3 V operation, output range, coating, and calibration. |
| Use a cheaper float-switch pack | $24.67 | AliExpress listing around $4.29 for the 1/5-piece variation | about $20.38 | High: listing variation, mechanical dimensions, wire length, and plastic compatibility must be verified. |
| Source EC11 encoder from LCSC | $19.30 | LCSC ALPSALPINE EC11E1820402 at about $1.616 each, 5 = $8.08 | $11.22 | Medium: verify footprint, shaft height, detents, and push-switch pins against Board B before buying. |
| Source SS34 from LCSC | $5.10 | LCSC BORN SS34, minimum 20 at about $0.0537 each, 20 = $1.07 | $4.03 | Low/medium: same SMA/DO-214AC class, but manufacturer changes. |
| Source ESP32-S3 module from LCSC | $28.30 | LCSC ESP32-S3-WROOM-1-N8 at about $4.773 each, 5 = $23.87 | $4.43 | Low/medium: same Espressif module target, but supplier/shipping changes. |
| Source AP63203 from LCSC | $4.00 | LCSC AP63203WU-7 at about $0.4705 each, 5 = $2.35 | $1.65 | Low/medium: same manufacturer part; savings only matter if already ordering from LCSC. |

If every option above works, the paper total drops from $275.10 to about $177.10. That is the aggressive-cost case and includes high-risk module substitutions.

Conservative supplier-only swaps, keeping DFRobot moisture sensors and PMD Way reservoir switches and not changing the power supplies, lower the total only to about $253.78. With the lower-cost adapters included, it becomes about $221.73.

## Recommended Path

1. Keep the exact PCB design.
2. Do not change the ESP32, AP63203, SS34, or EC11 footprints unless the alternate part drawings are checked against the current footprints.
3. Use LCSC for the AP63203, SS34, ESP32 module, and EC11 only if shipping is already justified by the order. Otherwise, DigiKey/Mouser consolidation may be cheaper at checkout.
4. For the moisture sensor and float switch, buy one cheap sample first if time allows. These are the biggest savings, but they are also the easiest place to lose reliability.
5. Do not cheap out blindly on mains power. Using adapters you already own is fine for prototypes; buying unknown wall adapters for deployed units is a safety/reliability tradeoff.

## Not Worth Changing Right Now

- PCB fabrication: Board A and Board B are already cheap. Combining them into a breakaway panel is not worth the added layout/manufacturing risk for this first order.
- OLED: Makerfabs is already $3.80 each at qty 5 and gives a clear module target. Cheaper marketplace OLEDs exist, but pin order is the main risk.
- Pump: cheaper international pump listings exist, but the selected Gikfun pump pack is already reasonable and has a known 3 V to 5 V target. Pump current/noise is a bring-up risk, so changing it for small savings is not the first move.
- Passives: the total line cost is too small to matter unless combined with a broader LCSC/Mouser consolidation.

## Sources Checked

- xUmp 5 V / 2 A adapter: https://www.xump.com/science/fast-usb-charger-power-supply-5v-2a.cfm
- AliExpress/PriceArchive generic capacitive sensor: https://ms.pricearchive.org/aliexpress.com/item/1005008718213399
- AliExpress/PriceArchive float-switch listing: https://no.pricearchive.org/aliexpress.com/item/1005009114140390
- LCSC ESP32-S3-WROOM-1-N8: https://www.lcsc.com/product-image/C2913198.html
- LCSC AP63203WU-7: https://www.lcsc.com/product-detail/C780769.html
- LCSC BORN SS34: https://www.lcsc.com/product-detail/C266553.html
- LCSC ALPSALPINE EC11E1820402: https://www.lcsc.com/product-detail/C361167.html
- Makerfabs OLED baseline: https://www.makerfabs.com/0-96-inch-i2c-oled-128x64-blue.html
- Thingbits low-cost 3 V to 5 V pump reference: https://www.thingbits.in/products/mini-vertical-submersible-pump-3v-to-5v-dc
- DFRobot SEN0193 baseline: https://www.dfrobot.com/product-1385.html/
- PMD Way float-switch baseline: https://pmdway.com/products/plastic-vertical-float-switches-five-pack

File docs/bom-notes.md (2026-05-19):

# Self-Watering Flower Pot V2 BOM Notes

This is a planning BOM, not a final purchasing list. Confirm exact part numbers, footprints, voltage ratings, current ratings, and availability before ordering. The current 5-system minimum-buy estimate is in `docs/total-bom-5-sets.md` and `fabrication/bom/total-bom-5-sets.csv`; possible lower-cost substitutions are in `docs/bom-cost-reduction-options.md`.

## Preferred Rev-A Parts

| Function | Preferred part / style | Notes |
|---|---|---|
| MCU | ESP32-S3-WROOM-1-N8 | Module, not dev board. Confirm footprint and antenna keepout. |
| Input power | USB-C 5V sink | Include CC resistors if using a bare receptacle. Use a dedicated 5 V, >=2 A USB adapter or power bank for pump operation. |
| 3.3V regulator | AP63203WU-7 | Check datasheet layout, inductor, feedback, and package. |
| Buck inductor | 3.9uH shielded power inductor | Confirm saturation current, DCR, pad fit, and height. |
| Buck output caps | 2 x 22uF 6.3V X7R 0805 | Place both close to the AP63203 output path. |
| Pump switch | AO3400A N-MOSFET | Confirm current and thermal margin for selected pump. |
| Flyback diode | SS34 or similar | Across pump/load path, orientation critical. |
| Pump rail bulk cap | 100uF 10V radial electrolytic or equivalent | Place near pump connector; observe polarity. |
| Pump | 5V mini submersible pump | Exact current draw must be measured or sourced from datasheet. |
| Moisture sensor | Capacitive analog module | Output must be 3.3V-safe. |
| Display | 0.96 inch SSD1306 I2C OLED | Confirm module pin order and voltage compatibility. |
| Encoder | EC11 rotary encoder with push | Confirm footprint variant and shaft/mechanical fit. |
| Error LED | Red LED plus resistor | Place where visible or route to UI board. |
| Connectors | JST-XH preferred | Confirm pitch, footprint, current, and cable orientation. |
| Passives | 0805 | Easier hand soldering. |
| Debug | Test pads / UART header | Include `+5V`, `+3V3`, `GND`, `EN`, `BOOT`, `TXD`, `RXD`, `PUMP_GATE`, `MOISTURE_ADC`, `I2C_SDA`, `I2C_SCL`. |
| Bench accessories | USB-C data cable, 3.3 V USB-UART adapter, current-limited 5 V source | Needed for safe first flash and fallback programming. Never use 5 V UART logic. |

## Required BOM Categories

- USB-C receptacle and CC resistors.
- Input protection: optional polyfuse and/or TVS if selected. Rev A does not include these parts, so accept that risk before ordering or make a Rev A.1 ECO.
- Bulk input capacitance for pump transients.
- Buck regulator, inductor, input capacitor, two output capacitors, and bootstrap capacitor.
- ESP32 module and support parts for EN/BOOT/programming.
- MOSFET driver parts: MOSFET, gate resistor, gate pulldown, flyback diode.
- Pump connector and pump wiring.
- Moisture sensor connector and ADC filter/protection parts.
- Reservoir switch connector and pull resistor.
- Optional flow sensor connector and level shifting/protection if needed.
- OLED/encoder/UI connector parts.
- LEDs and current-limiting resistors.
- Mounting holes and mechanical hardware.

## Footprints To Verify Before Ordering

- USB-C connector footprint against the exact part drawing.
- AP63203 package and recommended land pattern.
- Inductor pad size and height.
- ESP32-S3-WROOM-1 module footprint and antenna keepout.
- AO3400A SOT-23 pinout.
- SS34 package and polarity marking.
- JST connector pitch and pin 1 orientation.
- OLED header pin order.
- EC11 encoder mounting tabs and switch pins.
- Mounting hole diameter and enclosure hardware.

## Unknowns To Resolve

- Exact pump current draw and stall/startup behavior.
- Whether to accept Rev A without USB input fuse/current limiting and USB ESD protection.
- Whether ESP32 brownout testing requires a Rev A.1 local U1 bulk capacitor.
- Exact moisture sensor module pin order and output range.
- Exact OLED module pin order.
- Whether UI is on the main PCB or a cabled daughterboard.
- Exact USB-C receptacle part; Rev A schematic uses the 16-pin USB2 symbol with SBU pins no-connected.
- Exact enclosure mounting constraints.
- Target PCB manufacturer minimum trace/space, drill, and copper weight.

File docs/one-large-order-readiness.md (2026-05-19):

# One Large Order Readiness

Date: 2026-05-19

## Status

CAD package ready for manufacturer preview, with pre-order hardening notes added.

Board A and Board B now both pass ERC, DRC, and schematic-parity checks with 0 violations and 0 unconnected pads. Board A Gerbers, drill files, STEP, schematic PDF, routing review files, and 3D review images were regenerated after the four open connections were fixed and zones were refilled.

Do not check out the order until the Gerber zips are uploaded to the PCB manufacturer's viewer and visually inspected. The purchasing BOM now has a 5-system minimum-buy estimate in `fabrication/bom/total-bom-5-sets.csv`, but cart totals still need one last checkout refresh for shipping, taxes, tariffs, and supplier stock.

The hardening review did not find a CAD-clean blocker. It did identify prototype constraints that must be accepted before ordering Rev A: no USB input fuse/current limiter, no USB data ESD array, and no extra board-level ESP32 bulk capacitor directly beside U1. See `docs/pre-order-hardening-review.md`.

## Board A

Current checks:

- `reports/erc-order-batch-board-a.txt`: 0 violations.
- `reports/drc-order-batch-board-a.txt`: 0 violations, 0 unconnected pads.
- `reports/drc-order-batch-board-a-parity.txt`: 0 violations, 0 unconnected pads, 0 schematic parity issues.
- `reports/erc-hardening-board-a.txt`: 0 violations.
- `reports/drc-hardening-board-a.txt`: 0 violations, 0 unconnected pads.
- `reports/drc-hardening-board-a-parity.txt`: 0 violations, 0 unconnected pads, 0 schematic parity issues.

The four previous ordering blockers were fixed:

- `R8` pad 1 to `Net-(J4-Pin_1)` reservoir switch signal.
- `C4` pad 1 to `Net-(TP5-Pin_1)` optional moisture ADC filter/test node.
- `R6` pad 2 to `Net-(J6-Pin_3)` SDA pullup branch.
- `U1` pad 18 to `J6` pin 5 / `Net-(J6-Pin_5)` encoder A.

Board A package regenerated in this pass:

- Gerbers: `fabrication/board_a/gerbers/`
- Drill files and drill maps: `fabrication/board_a/drill/`
- Fab zip: `fabrication/board_a/Self-Watering_Flower_Pot_Board_A_fab.zip`
- STEP: `mechanical/Self-Watering_Flower_Pot_Board_A.step`
- Schematic PDF: `outputs/Self-Watering_Flower_Pot_Board_A_schematic.pdf`
- Routing review SVG/PDF: `outputs/Self-Watering_Flower_Pot_Board_A_routing.svg`, `outputs/Self-Watering_Flower_Pot_Board_A_routing.pdf`
- 3D review images: `outputs/Self-Watering_Flower_Pot_Board_A_3d_top.png`, `outputs/Self-Watering_Flower_Pot_Board_A_3d_bottom.png`

## Board B

Current checks:

- `board_b_ui/reports/erc-order-batch-board-b.txt`: 0 violations.
- `board_b_ui/reports/drc-order-batch-board-b.txt`: 0 violations, 0 unconnected pads.
- `board_b_ui/reports/drc-order-batch-board-b-parity.txt`: 0 violations, 0 unconnected pads, 0 schematic parity issues.
- `board_b_ui/reports/erc-hardening-board-b.txt`: 0 violations.
- `board_b_ui/reports/drc-hardening-board-b.txt`: 0 violations, 0 unconnected pads.
- `board_b_ui/reports/drc-hardening-board-b-parity.txt`: 0 violations, 0 unconnected pads, 0 schematic parity issues.

Board B package refreshed in this pass:

- Gerbers: `fabrication/board_b/gerbers/`
- Drill files and drill maps: `fabrication/board_b/drill/`
- Fab zip: `fabrication/board_b/Self-Watering_UI_Board_B_fab.zip`
- STEP: `board_b_ui/mechanical/Self-Watering_UI_Board_B.step`
- Schematic PDF: `board_b_ui/outputs/Self-Watering_UI_Board_B_schematic.pdf`
- Routing review SVG/PDF: `board_b_ui/outputs/Self-Watering_UI_Board_B_routing.svg`, `board_b_ui/outputs/Self-Watering_UI_Board_B_routing.pdf`
- 3D review images: `board_b_ui/outputs/Self-Watering_UI_Board_B_3d_top.png`, `board_b_ui/outputs/Self-Watering_UI_Board_B_3d_bottom.png`

Known acceptable Board B issue:

- KiCad still cannot load the EC11 encoder 3D model during STEP export. The pads and holes are present; the exported STEP may omit the encoder body. Check actual knob/shaft clearance against the enclosure manually.

## BOM Files

Generated KiCad BOM exports:

- Board A: `fabrication/bom/board_a-kicad-bom.csv`
- Board B: `fabrication/bom/board_b-kicad-bom.csv`

Order-readiness purchasing BOM:

- `fabrication/bom/order-readiness-purchasing-bom.csv`

5-system minimum-buy BOM:

- `fabrication/bom/total-bom-5-sets.csv`
- `docs/total-bom-5-sets.md`
- Cost-reduction options: `docs/bom-cost-reduction-options.md`

Current 5-system BOM estimate before shipping, tax, tariffs, tools, and enclosure materials:

- $275.10 including 5 power supplies, bench USB-C cable, fallback USB-UART adapter, and mounting hardware kits.
- $205.10 without power supplies and mounting hardware.
- $191.10 without power supplies, mounting hardware, bench USB-C cable, and USB-UART adapter.

Live supplier findings captured in the purchasing BOM:

- Critical ICs and USB-C connector are available from DigiKey in low quantities.
- Board B right-angle 9-pin JST XH header is available from distributor listings such as Newark/Mouser in low quantities.
- Some Board A JST XH natural top-entry headers had weak distributor stock during this check; use stocked exact-footprint equivalents, wait for incoming stock, or recheck equivalent JST XH color/key variants before buying.
- The L1 candidate is electrically reasonable, but its body is 6.0 mm x 6.0 mm and must be checked against the current `Inductor_SMD:L_Bourns_SRN6045TA` footprint before ordering.
- The OLED module is not locked until the actual module pin order is visually confirmed as `GND, VCC, SCL, SDA`.
- Do not buy a 12 V pump for the current board. Board A switches USB 5 V, so use a small 3 V to 5 V or 5 V pump only.
- Buy a dedicated 5 V, >=2 A USB adapter or USB power bank for pump tests. Do not run the pump from a laptop USB port.
- Buy a real USB-C data cable and a 3.3 V USB-UART adapter for fallback flashing through J7.

## Final Order Gate

Before ordering both boards and parts together:

1. Upload both final Gerber zip packages to the PCB manufacturer's previewer and inspect outlines, holes, copper, silkscreen, and solder mask.
2. Recheck Board A `J6` against Board B `J1`: `1=+3V3`, `2=GND`, `3=SDA`, `4=SCL`, `5=ENC_A`, `6=ENC_B`, `7=ENC_SW`, `8=ERROR_LED`, `9=STATUS_LED`.
3. In KiCad 3D viewer or the enclosure CAD, confirm Board B back-side cable direction, OLED fit, encoder clearance, LED visibility, and mounting holes.
4. Refresh the purchasing BOM prices and stock immediately before checkout.
5. Resolve the remaining BOM warning items: L1 footprint fit, JST stocked equivalents, OLED pin order, EC11 shaft/panel clearance, reservoir switch geometry, and optional flow-sensor level safety.
6. Explicitly accept the Rev A protection tradeoff documented in `docs/pre-order-hardening-review.md`, or stop and make a Rev A.1 ECO for USB fuse/ESD/local ESP32 bulk capacitance.

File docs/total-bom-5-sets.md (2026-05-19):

# Total BOM For 5 Self-Watering Flower Pot V2 Units

Date checked: 2026-05-19

This is the minimum-buy order estimate for building 5 complete Rev A systems: 5 Board A PCBs, 5 Board B UI PCBs, and enough parts to assemble and operate 5 units. It includes current supplier minimum order quantities and pack sizes where they matter.

It excludes shipping, sales tax, tariffs, tools, solder/flux/wire, enclosure/base material, and optional flow sensors. Final cart totals can move noticeably because the order touches several suppliers.

## Total

| Scope | Estimated minimum checkout cost |
|---|---:|
| 5 complete systems, including 5 power supplies, bench USB-C cable, fallback USB-UART, and mounting hardware kits | $275.10 |
| Same order without power supplies and mounting hardware | $205.10 |
| Bare electronics/modules only, also excluding bench USB-C cable and USB-UART adapter | $191.10 |

Optional flow sensing is not included. If you add one flow sensor per unit, budget roughly another $45 plus any level-shifting/protection parts if the selected flow sensor outputs 5 V pulses.

## Major Cost Drivers

| Item | Buy quantity | Estimated line cost | Note |
|---|---:|---:|---|
| ESP32-S3-WROOM-1-N8 modules | 5 | $28.30 | DigiKey low-quantity price. |
| EC11 encoders | 5 | $19.30 | Mouser qty-5 price; verify shaft/panel clearance. |
| OLED modules | 5 | $19.00 | Makerfabs module; verify `GND,VCC,SCL,SDA` pin order. |
| Pump packs | 2 packs / 8 pumps | $23.96 | Gikfun sells the selected pump as a 4-pack. |
| Moisture sensors | 5 | $28.50 | DFRobot qty-5 price tier. |
| Reservoir float switches | 1 five-pack | $24.67 | Mechanical fit still depends on the reservoir/base design. |
| 5 V >=2 A power supplies | 5 | $50.00 | Needed if all 5 units will be deployed independently. |

## Minimum-Buy Notes

- The Board B right-angle 9-pin JST header source found has a minimum order of 10, so the BOM buys 10 even though only 5 are installed.
- The selected pump is sold as a 4-pack, so 5 systems require buying 2 packs and leaving 3 spare pumps.
- The JST crimp-contact line is the exact minimum count for pump, reservoir, moisture, and Board A to Board B UI cables: 125 contacts. Buy more in real life; hand crimping small contacts wastes parts.
- DNP capacitors are not included in the minimum build: Board A `C4` and Board B `C1-C3`.
- Optional flow hardware is not included. The Board A connector is populated, but the board works without a flow sensor.

## Lock Before Checkout

- Confirm `L1` physical fit against `Inductor_SMD:L_Bourns_SRN6045TA`.
- Confirm the exact USB-C suffix matches the KiCad USB4105 footprint.
- Confirm JST header orientation and pin 1 marks before ordering cable parts.
- Confirm OLED module pin order is `GND,VCC,SCL,SDA`.
- Confirm EC11 encoder shaft height and knob clearance against the UI panel.
- Confirm the selected reservoir switch physically fits the base/reservoir.
- Upload both Gerber zips to the PCB manufacturer viewer and inspect every layer before checkout.

## Files

- Detailed CSV: `fabrication/bom/total-bom-5-sets.csv`
- Board A fab zip: `fabrication/board_a/Self-Watering_Flower_Pot_Board_A_fab.zip`
- Board B fab zip: `fabrication/board_b/Self-Watering_UI_Board_B_fab.zip`
- Downloads copies:
  - `C:\Users\chesk\Downloads\Self-Watering_Flower_Pot_Board_A_fab.zip`
  - `C:\Users\chesk\Downloads\Self-Watering_UI_Board_B_fab.zip`

## Sources Checked

- JLCPCB prototype pricing page: https://jlcpcb.com/?from=getquote
- ESP32-S3-WROOM-1-N8: https://www.digikey.com/en/products/detail/espressif-systems/ESP32-S3-WROOM-1-N8/15200089
- AP63203WU-7: https://www.digikey.com/en/products/detail/diodes-incorporated/AP63203WU-7/9858426
- USB4105-GF-A: https://www.digikey.com/en/products/detail/gct/USB4105-GF-A/11198441
- ASPI-0628-3R9M-T1 inductor candidate: https://www.digikey.com/en/products/detail/abracon-llc/ASPI-0628-3R9M-T1/5043506
- AO3400A: https://www.lcsc.com/product-detail/MOSFET_Alpha-Omega-Semicon-AO3400A_C20917.html
- SS34-E3/57T: https://www.digikey.com/en/products/detail/vishay-general-semiconductor-diodes-division/SS34-E3-57T/1091554
- JST XH cable housings/contacts and EC11 encoder: Mouser/Newark/TrustedParts links in the CSV.
- Makerfabs OLED: https://www.makerfabs.com/0-96-inch-i2c-oled-128x64-blue.html
- Gikfun pump pack: https://gikfun.com/products/gikfun-dc-3v-5v-micro-submersible-mini-water-pump-pack-of-4pcs
- DFRobot SEN0193 moisture sensor: https://www.dfrobot.com/product-1385.html/
- PMD Way float-switch five-pack: https://pmdway.com/products/plastic-vertical-float-switches-five-pack

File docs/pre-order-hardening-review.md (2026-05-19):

# Pre-Order Hardening Review

Date: 2026-05-19

## Status

Board A and Board B remain CAD-clean after the hardening review:

- Board A ERC: `reports/erc-hardening-board-a.txt`, 0 violations.
- Board A DRC: `reports/drc-hardening-board-a.txt`, 0 violations, 0 unconnected items.
- Board A schematic parity: `reports/drc-hardening-board-a-parity.txt`, 0 violations, 0 unconnected items, 0 schematic parity issues.
- Board B ERC: `board_b_ui/reports/erc-hardening-board-b.txt`, 0 violations.
- Board B DRC: `board_b_ui/reports/drc-hardening-board-b.txt`, 0 violations, 0 unconnected items.
- Board B schematic parity: `board_b_ui/reports/drc-hardening-board-b-parity.txt`, 0 violations, 0 unconnected items, 0 schematic parity issues.
- PCB net audit: `reports/pre-order-hardening-net-audit.txt`.

## Decision

Do not make a last-minute PCB ECO before ordering Rev A unless you explicitly decide to trade schedule for added protection. The current board is acceptable as a careful prototype if these rules are followed:

- Use a dedicated 5 V, >=2 A USB adapter or USB power bank for pump operation.
- Do not run the pump from a laptop USB port.
- First flash and first rail checks happen with the pump disconnected.
- Use current limiting during first power-up and first pump pulses.
- Keep every external sensor signal at ESP32-safe 3.3 V logic or analog levels.

The review found useful Rev A.1/product improvements, but not a reason to disturb the current CAD-clean Rev A package:

- Add a USB input polyfuse or current-limited switch.
- Add USB D+/D- ESD protection, and optionally VBUS TVS protection.
- Add a local board-level 10 uF ESP32 bulk capacitor near U1 `3V3/GND` if layout space allows.
- Add physical BOOT and RESET/EN buttons if J7 will be hard to reach in the enclosure.

## Programming Path

Primary path:

1. Use a real USB-C data cable.
2. Plug Board A into the computer with the pump disconnected.
3. Flash through ESP32-S3 native USB on Board A USB-C.

Fallback path through J7:

1. Use a 3.3 V USB-UART adapter only.
2. Connect adapter `GND`, `TX`, and `RX` to J7. Do not connect any 5 V UART signal.
3. Hold J7 `IO0/BOOT` low.
4. Pulse J7 `EN` low, then release `EN`.
5. Release or keep `IO0/BOOT` low as required by the flashing tool, then upload with ESP-IDF, Arduino, or esptool.

Do not use 5 V UART levels on ESP32 pins.

## USB And Power Budget

The two 5.1k CC resistors are USB-C sink-identification resistors. They do not power the board and they do not limit current. The actual power path is:

- USB-C VBUS provides the `+5V` rail.
- `+5V` feeds the pump connector and the AP63203 buck input.
- AP63203 generates `+3V3` for the ESP32, UI, and sensors.
- The ESP32 controls only the MOSFET gate; the pump current does not flow through an ESP32 GPIO.

Budget the prototype conservatively:

- ESP32-S3 plus Wi-Fi current spikes: plan up to roughly 0.5 A on `+3V3`.
- OLED, sensors, LEDs, and pullups are small compared with the ESP32 and pump.
- The selected pump listing gives about 0.18 A running current, but startup and stall current must be measured on arrival.
- Use 5 V, >=2 A for pump testing so startup surge does not brown out the ESP32.

## Protection And Noise Review

Present on Rev A:

- Pump low-side AO3400A switch.
- 220 ohm pump gate resistor.
- 100k pump gate pulldown.
- SS34 flyback diode to the `+5V` pump rail.
- 100 uF pump bulk capacitor.
- Moisture ADC series resistor and optional filter footprint.
- Backup J7 debug/programming header.

Not present on Rev A:

- USB input fuse or current-limited switch.
- USB data-line ESD array.
- Dedicated board-level ESP32 local bulk capacitor placed right at U1.

Prototype acceptance notes:

- The missing fuse/ESD parts are acceptable for a bench prototype, but this board should not be treated as a finished consumer product.
- If ESP32 brownouts occur during Wi-Fi or pump pulses, first test with a stronger 5 V source and pump disconnected. If the problem remains, add temporary capacitance between J7 `3V3` and `GND` for diagnosis or make a Rev A.1 PCB ECO with a local U1 bulk capacitor.
- If a flow sensor or other external module outputs 5 V pulses, do not connect it directly to ESP32 GPIO. Use a 3.3 V-safe sensor output or add level shifting before populating that option.

## Mechanical And Parts Review

Still confirm before checkout:

- L1 body and pads physically match the selected inductor footprint.
- USB-C exact part suffix matches the KiCad footprint and exits the enclosure correctly.
- OLED module pin order is `GND, VCC, SCL, SDA`.
- EC11 shaft height and knob clearance fit Board B and the front panel.
- JST header orientation and mating cable direction match the actual enclosure.
- Reservoir switch geometry matches the reservoir/base design.
- Board B back-side J1 cable exits in the intended direction.

## Order Gate

Before buying:

1. Upload both Gerber zip files to the PCB manufacturer's viewer.
2. Inspect outline, drill, solder mask, silkscreen, copper pours, USB-C pads, antenna keepout, and pin-1 labels.
3. Refresh live BOM stock and prices.
4. Decide explicitly that Rev A is accepted without USB fuse/ESD/local-U1-bulk ECO.
5. Buy a 5 V, >=2 A USB power source, a real USB-C data cable, and a 3.3 V USB-UART adapter for fallback programming.

## References

- AP63203: https://www.diodes.com/part/view/AP63203
- AP63203 DigiKey listing: https://www.digikey.com/en/products/detail/diodes-incorporated/AP63203WU-7/9858426
- ESP32-S3 boot mode selection: https://docs.espressif.com/projects/esptool/en/latest/esp32s3/advanced-topics/boot-mode-selection.html
- ESP32-S3 serial connection and native USB notes: https://docs.espressif.com/projects/esp-idf/en/stable/esp32s3/get-started/establish-serial-connection.html
- GCT USB4105 spec: https://gct.co/files/specs/usb4105-spec.pdf
- Gikfun pump listing: https://gikfun.com/products/gikfun-dc-3v-5v-micro-submersible-mini-water-pump-pack-of-4pcs

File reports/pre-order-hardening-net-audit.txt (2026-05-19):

Pre-order hardening PCB net audit
Generated from KiCad PCB files; this is a design-data audit, not a substitute for visual Gerber review.

Board A programming and USB
- J1: USB-C 5V + USB2 | Connector_USB:USB_C_Receptacle_GCT_USB4105-xx-A_16P_TopMnt_Horizontal | F.Cu | 75.28,111.54 mm
- U1: ESP32-S3-WROOM-1-N8 | RF_Module:ESP32-S3-WROOM-1 | F.Cu | 80.73,84.48 mm
- J7: DEBUG 3V3/GND/TX/RX/EN/BOOT | Connector_PinHeader_2.54mm:PinHeader_1x06_P2.54mm_Vertical | F.Cu | 106.85,100.75 mm
  J1 VBUS pads A4/A9/B4/B9: +5V, +5V, +5V, +5V
  J1 D- / D+: Net-(U1-USB_D-) / Net-(U1-USB_D+)
  U1 USB_D- / USB_D+: pad13=Net-(U1-USB_D-), pad14=Net-(U1-USB_D+)
  J7 backup header: 1=+3V3, 2=GND, 3=Net-(J7-Pin_3), 4=Net-(J7-Pin_4), 5=Net-(J7-Pin_5), 6=Net-(J7-Pin_6)

Board A power and pump
- U2: AP63203WU-7 | Package_TO_SOT_SMD:TSOT-23-6 | F.Cu | 111.38,58.60 mm
- L1: 3.9uH shielded >=3A Isat | Inductor_SMD:L_Bourns_SRN6045TA | F.Cu | 109.28,85.58 mm
- C1: 10uF 10V X7R input | Capacitor_SMD:C_0805_2012Metric | F.Cu | 111.37,99.96 mm
- C2: 22uF 6.3V X7R output | Capacitor_SMD:C_0805_2012Metric | F.Cu | 111.37,102.97 mm
- C5: 22uF 6.3V X7R output | Capacitor_SMD:C_0805_2012Metric | F.Cu | 111.37,112.00 mm
- C6: 100uF 10V pump bulk | Capacitor_THT:CP_Radial_D6.3mm_P2.50mm | F.Cu | 108.07,77.88 mm
- J2: PUMP 5V | Connector_JST:JST_XH_B2B-XH-A_1x02_P2.50mm_Vertical | F.Cu | 98.58,101.83 mm
- Q1: AO3400A | Package_TO_SOT_SMD:SOT-23 | F.Cu | 111.26,63.05 mm
- D1: SS34 flyback | Diode_SMD:D_SMA | F.Cu | 109.33,91.63 mm
- R4: 220R gate | Resistor_SMD:R_0805_2012Metric | F.Cu | 62.82,107.73 mm
- R5: 100k pulldown | Resistor_SMD:R_0805_2012Metric | F.Cu | 62.82,110.68 mm
  U2 power: VIN pads 2/3=+5V/+5V; OUT pad1=+3V3; GND pad4=GND
  Pump connector J2: pin1=+5V, pin2=Net-(D1-A)
  Pump switch Q1: gate=Net-(Q1-G), source=GND, drain=Net-(D1-A)
  Flyback D1: cathode/pad1=+5V, anode/pad2=Net-(D1-A)
  Pump gate network: R4 pad1=Net-(U1-IO4), R4 pad2=Net-(Q1-G); R5 pad2=GND

Board A to Board B UI cable parity
  pin 1: Board A J6=+3V3; Board B J1=/+3V3
  pin 2: Board A J6=GND; Board B J1=/GND
  pin 3: Board A J6=Net-(J6-Pin_3); Board B J1=/SDA
  pin 4: Board A J6=Net-(J6-Pin_4); Board B J1=/SCL
  pin 5: Board A J6=Net-(J6-Pin_5); Board B J1=/ENC_A
  pin 6: Board A J6=Net-(J6-Pin_6); Board B J1=/ENC_B
  pin 7: Board A J6=Net-(J6-Pin_7); Board B J1=/ENC_SW
  pin 8: Board A J6=Net-(J6-Pin_8); Board B J1=/ERROR_LED
  pin 9: Board A J6=Net-(J6-Pin_9); Board B J1=/STATUS_LED

Board B UI interface
  J2 OLED: 1=/GND, 2=/+3V3, 3=/SCL, 4=/SDA
  SW1 encoder: A=/ENC_A, B=/ENC_B, C=/GND, S1=/ENC_SW, S2=/GND

Hardening observations
- Native USB data and backup J7 boot/debug path are present in PCB net data.
- Pump is switched low-side; ESP32 GPIO only drives the MOSFET gate through a resistor and pulldown.
- USB-C CC resistors are sink-identification resistors only; they do not limit pump or ESP current.
- No dedicated USB input fuse/current limiter or USB data ESD array was found in placed Board A parts.
- No added board-level ESP32 local bulk capacitor near U1 was found beyond the regulator output capacitors and module internal capacitance.

Result
CAD checks remain clean. Ordering decision should depend on accepting Rev A without fuse/ESD/local U1 bulk ECO, plus strict bring-up current limiting and pump-disconnected first flash.

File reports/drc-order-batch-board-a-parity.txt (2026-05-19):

** Drc report for SmartWateringFlowerPot.kicad_pcb **
** Created on 2026-05-19T07:53:03-0500 **

** Found 0 DRC violations **

** Found 0 unconnected pads **

** Found 0 Footprint errors **

** End of Report **

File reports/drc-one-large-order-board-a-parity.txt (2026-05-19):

** Drc report for SmartWateringFlowerPot.kicad_pcb **
** Created on 2026-05-18T21:02:20-0500 **

** Found 2 DRC violations **
[silk_overlap]: Silkscreen overlap
    Rule: board setup constraints silk; warning
    @(56.8000 mm, 56.8000 mm): Rectangle on F.Silkscreen
    @(89.9300 mm, 71.5800 mm): Segment of U1 on F.Silkscreen
[silk_overlap]: Silkscreen overlap
    Rule: board setup constraints silk; warning
    @(71.5300 mm, 71.5800 mm): Segment of U1 on F.Silkscreen
    @(56.8000 mm, 56.8000 mm): Rectangle on F.Silkscreen

** Found 4 unconnected pads **
[unconnected_items]: Missing connection between items
    Local override; error
    @(81.7150 mm, 98.2800 mm): Track [Net-(J4-Pin_1)] on F.Cu, length 0.4950 mm
    @(66.3175 mm, 110.6800 mm): Pad 1 [Net-(J4-Pin_1)] of R8 on F.Cu
[unconnected_items]: Missing connection between items
    Local override; error
    @(110.4200 mm, 108.9900 mm): Pad 1 [Net-(TP5-Pin_1)] of C4 on F.Cu
    @(87.4618 mm, 84.6082 mm): Track [Net-(TP5-Pin_1)] on B.Cu, length 11.5743 mm
[unconnected_items]: Missing connection between items
    Local override; error
    @(64.6800 mm, 101.8300 mm): Track [Net-(J6-Pin_3)] on B.Cu, length 0.5304 mm
    @(63.7325 mm, 113.6300 mm): Pad 2 [Net-(J6-Pin_3)] of R6 on F.Cu
[unconnected_items]: Missing connection between items
    Local override; error
    @(69.6800 mm, 101.8300 mm): PTH pad 5 [Net-(J6-Pin_5)] of J6
    @(77.5550 mm, 96.9800 mm): Pad 18 [Net-(J6-Pin_5)] of U1 on F.Cu

** Found 0 Footprint errors **

** End of Report **

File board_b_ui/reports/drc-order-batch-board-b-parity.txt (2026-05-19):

** Drc report for BoardB_UI.kicad_pcb **
** Created on 2026-05-19T07:53:02-0500 **

** Found 0 DRC violations **

** Found 0 unconnected pads **

** Found 0 Footprint errors **

** End of Report **

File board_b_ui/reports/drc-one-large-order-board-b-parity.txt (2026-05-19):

** Drc report for BoardB_UI.kicad_pcb **
** Created on 2026-05-18T21:02:47-0500 **

** Found 0 DRC violations **

** Found 0 unconnected pads **

** Found 0 Footprint errors **

** End of Report **

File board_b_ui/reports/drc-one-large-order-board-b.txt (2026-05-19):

** Drc report for BoardB_UI.kicad_pcb **
** Created on 2026-05-18T21:02:42-0500 **

** Found 0 DRC violations **

** Found 0 unconnected pads **

** Found 0 Footprint errors **

** End of Report **

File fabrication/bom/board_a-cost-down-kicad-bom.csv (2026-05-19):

Refs | Value | Footprint | Qty | DNP
C1 | 10uF 10V X7R input | Capacitor_SMD:C_0805_2012Metric | 1
C2 | 22uF 6.3V X7R output | Capacitor_SMD:C_0805_2012Metric | 1
C3 | 100nF 10V BST | Capacitor_SMD:C_0805_2012Metric | 1
C5 | 22uF 6.3V X7R output | Capacitor_SMD:C_0805_2012Metric | 1
C6 | 100uF 10V pump bulk | Capacitor_THT:CP_Radial_D6.3mm_P2.50mm | 1
D1 | SS34 flyback | Diode_SMD:D_SMA | 1
D2 | ERROR red | LED_SMD:LED_0805_2012Metric | 1
D3 | STATUS green | LED_SMD:LED_0805_2012Metric | 1
J1 | USB-C 5V + USB2 | Connector_USB:USB_C_Receptacle_GCT_USB4105-xx-A_16P_TopMnt_Horizontal | 1
J2 | PUMP 5V | Connector_JST:JST_XH_B2B-XH-A_1x02_P2.50mm_Vertical | 1
J3 | MOISTURE | Connector_JST:JST_XH_B3B-XH-A_1x03_P2.50mm_Vertical | 1
J7 | DEBUG 3V3/GND/TX/RX/EN/BOOT | Connector_PinHeader_2.54mm:PinHeader_1x06_P2.54mm_Vertical | 1
L1 | 3.9uH shielded >=3A Isat | Inductor_SMD:L_Bourns_SRN6045TA | 1
Q1 | AO3400A | Package_TO_SOT_SMD:SOT-23 | 1
R1 | 5.1k CC1 | Resistor_SMD:R_0805_2012Metric | 1
R2 | 5.1k CC2 | Resistor_SMD:R_0805_2012Metric | 1
R3 | 10k EN pullup | Resistor_SMD:R_0805_2012Metric | 1
R4 | 220R gate | Resistor_SMD:R_0805_2012Metric | 1
R5 | 100k pulldown | Resistor_SMD:R_0805_2012Metric | 1
R10 | 1k ADC series | Resistor_SMD:R_0805_2012Metric | 1
R11 | 330R error LED | Resistor_SMD:R_0805_2012Metric | 1
R12 | 330R status LED | Resistor_SMD:R_0805_2012Metric | 1
TP1 | +5V TP | TestPoint:TestPoint_Pad_D1.5mm | 1
TP2 | GND TP | TestPoint:TestPoint_Pad_D1.5mm | 1
TP3 | +3V3 TP | TestPoint:TestPoint_Pad_D1.5mm | 1
TP4 | PUMP_GATE TP | TestPoint:TestPoint_Pad_D1.5mm | 1
TP5 | MOISTURE_ADC TP | TestPoint:TestPoint_Pad_D1.5mm | 1
U1 | ESP32-S3-WROOM-1-N8 | RF_Module:ESP32-S3-WROOM-1 | 1
U2 | AP63203WU-7 | Package_TO_SOT_SMD:TSOT-23-6 | 1

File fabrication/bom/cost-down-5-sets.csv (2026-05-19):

Include_in_electronics_total | Category | Designators | Item | Orderable_part_or_target | Required_for_5_units | MOQ_or_pack_basis | Buy_qty | Estimated_line_usd | Status | Notes
YES | PCB | PCB-A | Bare main controller PCB | Self-Watering_Flower_Pot_Board_A_cost_down_fab.zip | 5 boards | Prototype PCB fab minimum usually 5 boards | 5 | 2.00 | CART_QUOTE | Estimate excludes PCB shipping, color/upcharge, taxes, and tariffs.
YES | Board A | U1 | ESP32-S3 module | Espressif ESP32-S3-WROOM-1-N8 | 5 | MOQ 1 cut tape | 5 | 28.30 | OK | Same controller as the two-board design; supports USB-C native programming.
YES | Board A | U2 | 3.3 V buck regulator | Diodes Inc AP63203WU-7 | 5 | MOQ 1 cut tape | 5 | 4.00 | OK | Fixed 3.3 V output part.
YES | Board A | J1 | USB-C receptacle | GCT USB4105-GF-A | 5 | MOQ 1 cut tape | 5 | 4.00 | OK | Matches the selected USB4105 16-pin top-mount footprint family.
YES | Board A | L1 | 3.9 uH shielded inductor | Abracon ASPI-0628-3R9M-T1 candidate | 5 | MOQ 1 cut tape | 5 | 1.75 | VERIFY_FOOTPRINT | Physically verify against Inductor_SMD:L_Bourns_SRN6045TA before checkout.
YES | Board A | Q1 | N-channel pump MOSFET | AOS AO3400A | 5 | Minimum 5, multiple 5 | 5 | 0.40 | OK | Logic-level SOT-23 low-side pump switch.
YES | Board A | D1 | Pump flyback diode | BORN SS34 or SMA SS34 equivalent | 5 | LCSC minimum 20 | 20 | 1.07 | OK_EQUIV | SMA/DO-214AC footprint; observe polarity.
YES | Board A | J2 | 2-pin JST-XH vertical pump header | JST B2B-XH-A-E(LF)(SN) or exact-footprint stocked equivalent | 5 | Qty 10 price tier assumed | 10 | 1.23 | OK_EQUIV | Only pump connector is required; extra headers are spares.
YES | Board A | J3 | 3-pin JST-XH vertical moisture header | JST B3B-XH-A-BK(LF)(SN) or exact-footprint stocked equivalent | 5 | Qty 10 price tier assumed | 10 | 1.65 | OK_EQUIV | Only moisture connector is required; extra headers are spares.
YES | Cables | J2 mating | 2-pin JST-XH housings | JST XHP-2 | 5 | Qty 10 price tier assumed | 10 | 0.59 | OK | Pump cable housings plus spares.
YES | Cables | J3 mating | 3-pin JST-XH housings | JST XHP-3 | 5 | MOQ 1, buy 5 minimum | 5 | 0.50 | OK | Moisture sensor cable housings.
YES | Cables | JST contacts | JST-XH crimp contacts | JST SXH-001T-P0.6 | 25 minimum contacts | Buy 100 because hand crimping wastes contacts | 100 | 4.20 | MINIMUM | Covers pump and moisture cables with useful spares.
YES | Board A | J7 | Debug header | Generic 2.54 mm single-row breakaway header | 30 pins | Two 40-pin strips assumed | 2 strips | 1.50 | OK | Covers five 1x6 debug headers.
YES | Board A | D2,D3 | 0805 red and green LEDs | Lite-On 0805 LED equivalents | 5 red plus 5 green | MOQ varies, buy 10 total | 10 | 1.30 | OK | Board A local error and status indicators.
YES | Board A | R11,R12 | 330 ohm 0805 LED resistors | Yageo RC0805FR-07330RL or equivalent | 10 | Qty 10 estimate | 10 | 0.34 | OK | Board A LED current limiting.
YES | Board A | R1,R2 | 5.1k 0805 USB-C CC resistors | Yageo RC0805FR-075K1L or equivalent | 10 | Qty 10 estimate | 10 | 0.34 | OK | USB-C sink CC resistors.
YES | Board A | R3 | 10k 0805 EN pullup | Yageo RC0805FR-0710KL or equivalent | 5 | Qty 25 estimate | 25 | 0.64 | OK | Extra 10k resistors become useful spares.
YES | Board A | R4 | 220 ohm 0805 pump gate resistor | Yageo RC0805FR-07220RL or equivalent | 5 | MOQ 1 estimate | 5 | 0.50 | OK | Gate series resistor.
YES | Board A | R5 | 100k 0805 pump gate pulldown | Yageo RC0805FR-07100KL or equivalent | 5 | MOQ 1 estimate | 5 | 0.50 | OK | Keeps pump gate off during reset/boot.
YES | Board A | R10 | 1k 0805 moisture ADC series resistor | Yageo RC0805FR-071KL or equivalent | 5 | MOQ 1 estimate | 5 | 0.50 | OK | Moisture ADC protection/series resistor.
YES | Board A | C1 | 10 uF 10 V X7R 0805 input capacitor | 10 uF 10 V X7R 0805 MLCC equivalent | 5 | MOQ 1 estimate | 5 | 1.60 | OK | Use at least 10 V rating.
YES | Board A | C2,C5 | 22 uF 6.3 V X5R 0805 output capacitors | Murata GRM21BR60J226ME39L or equivalent | 10 | Qty 10 estimate | 10 | 1.90 | OK | Two output capacitors per Board A.
YES | Board A | C3 | 100 nF 0805 bootstrap capacitor | 100 nF 0805 MLCC equivalent | 5 | MOQ 1 estimate | 5 | 0.50 | OK | C4 remains DNP optional ADC filter and is not included.
YES | Board A | C6 | 100 uF 10 V pump rail bulk capacitor | 100 uF 10 V radial electrolytic, 6.3 mm body, 2.50 mm pitch | 5 | MOQ 1 estimate | 5 | 3.25 | OK | Observe polarity.
YES | System | Pump | 3 V to 5 V mini submersible pump | Gikfun DC 3 V-5 V micro submersible pump pack of 4 | 5 pumps | Sold as 4-pack | 2 packs | 23.96 | PACK_OVERBUY | Buying two packs gives 8 pumps for 5 systems.
YES | System | Moisture sensor | Generic capacitive soil moisture sensor | Generic capacitive soil moisture sensor V1.2 or equivalent | 5 | Marketplace five-pack estimate | 5 | 4.25 | VERIFY_PIN_ORDER | Cable must adapt to actual module pin order; confirm 3.3 V operation and output range.
NO | Deferred UI | Board B, OLED, EC11, UI cable | Board B UI system | Deferred optional UI board | 0 | Not ordered for cost-down version | 0 | 0.00 | DEFERRED | Kept in repo, excluded from cost-down purchase.
NO | Optional sensing | RESERVOIR_SW pads | Reservoir float switch | 2-wire float switch selected after reservoir geometry is known | 0 | Optional only | 0 | 0.00 | OPTIONAL | Firmware default RESERVOIR_SENSOR_ENABLED=false.
NO | Optional sensing | FLOW_PULSE pads | Flow sensor | 3.3 V-safe pulse sensor or external level-shifted sensor | 0 | Optional only | 0 | 0.00 | OPTIONAL | Firmware default FLOW_SENSOR_ENABLED=false.
NO | Support accessory | Power source | 5 V >=2 A USB adapter or power bank | Low-cost 5 V / 2 A adapters | 5 if deployed | Five adapters estimate | 5 | 17.95 | ACCESSORY | Not included in electronics-only total; required for deployed pump testing unless already available.

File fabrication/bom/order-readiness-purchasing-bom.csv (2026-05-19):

Board_or_system | Designators | Item | Footprint_or_interface | Locked purchasing target | Required_qty | Recommended_buy_qty | Checked_source | Source_url | MOQ_or_pack_estimate | Estimated_checkout_cost_usd | Status | Notes
Order | Board A PCB | Bare PCB for main controller | Current KiCad Board A outline and drills | Board A current Gerber and drill package | 1 board | 5 boards | PCB fab viewer after Gerber upload |  | Manufacturer minimum usually 5 boards | TBD | OK_CHECK_PREVIEW | Board A now passes ERC/DRC/parity clean. Upload fabrication/board_a/Self-Watering_Flower_Pot_Board_A_fab.zip to the manufacturer viewer and inspect before checkout.
Order | Board B PCB | Bare PCB for UI daughterboard | Current KiCad Board B outline and drills | Board B current Gerber and drill package | 1 board | 5 boards | PCB fab viewer after Gerber upload |  | Manufacturer minimum usually 5 boards | TBD | OK_CHECK_PREVIEW | Board B is clean and refreshed. Upload fabrication/board_b/Self-Watering_UI_Board_B_fab.zip to the manufacturer viewer and inspect before checkout.
Board A | U1 | ESP32-S3 module | RF_Module:ESP32-S3-WROOM-1 | Espressif ESP32-S3-WROOM-1-N8 | 1 | 2 | DigiKey | https://www.digikey.com/en/products/detail/espressif-systems/ESP32-S3-WROOM-1-N8/15200089 | MOQ 1 cut tape | about 10-14 for 2 | OK | DigiKey listing showed active part and thousands in stock during live check.
Board A | U2 | 3.3 V buck regulator | Package_TO_SOT_SMD:TSOT-23-6 | Diodes Inc AP63203WU-7 | 1 | 5 | DigiKey | https://www.digikey.com/en/products/detail/diodes-incorporated/AP63203WU-7/9858426 | MOQ 1 cut tape | about 3-4 for 5 | OK | Fixed 3.3 V output version; keep datasheet layout rules around input cap, inductor, BST cap, and FB/GND pins.
Board A | J1 | USB-C receptacle | Connector_USB:USB_C_Receptacle_GCT_USB4105-xx-A_16P_TopMnt_Horizontal | GCT USB4105-GF-A | 1 | 3 | DigiKey | https://www.digikey.com/en/products/detail/gct/USB4105-GF-A/11198441 | MOQ 1 cut tape | about 2-3 for 3 | OK | Matches the selected 16-pin top-mount USB-C footprint family; verify exact suffix before buying.
Board A | L1 | Buck inductor 3.9 uH | Inductor_SMD:L_Bourns_SRN6045TA | Abracon ASPI-0628-3R9M-T1 candidate | 1 | 3 | DigiKey | https://www.digikey.com/en/products/detail/abracon-llc/ASPI-0628-3R9M-T1/5043506 | MOQ 1 cut tape | about 2 for 3 | VERIFY_FOOTPRINT | Electrical value is suitable, but body/pad fit must be checked against the current Bourns SRN6045TA footprint before purchase.
Board A | Q1 | Pump low-side MOSFET | Package_TO_SOT_SMD:SOT-23 | Alpha and Omega AO3400A | 1 | 10 | LCSC | https://www.lcsc.com/product-detail/MOSFET_Alpha-Omega-Semicon-AO3400A_C20917.html | MOQ 5, buy multiples of 5 | about 1 for 10 before shipping | OK | Logic-level N-MOSFET for 3.3 V gate drive; verify SOT-23 pinout G/S/D against KiCad footprint before assembly.
Board A | D1 | Pump flyback diode | Diode_SMD:D_SMA | Vishay SS34-E3/57T | 1 | 5 | DigiKey | https://www.digikey.com/en/products/detail/vishay-general-semiconductor-diodes-division/SS34-E3-57T/1091554 | MOQ 1 cut tape | about 3-4 for 5 | OK | SMA/DO-214AC style Schottky; observe polarity mark during assembly.
Board A | J2,J4 | 2-pin JST XH vertical headers | Connector_JST:JST_XH_B2B-XH-A_1x02_P2.50mm_Vertical | JST B2B-XH-A(LF)(SN) or stocked exact-footprint equivalent | 2 | 4 | Mouser | https://www.mouser.com/ProductDetail/JST-Commercial/B2B-XH-ALFSN?qs=cdbOS8ANM9DdcSn9qRmfCw%3D%3D | MOQ 1 but Mouser US showed 0 stock | about 1 if stocked | SOURCE_ALTERNATE | Mouser US showed 0 stock with incoming dates; find a stocked authorized equivalent or wait before buying.
Board A | J3,J5 | 3-pin JST XH vertical headers | Connector_JST:JST_XH_B3B-XH-A_1x03_P2.50mm_Vertical | JST B3B-XH-A(LF)(SN) or stocked exact-footprint equivalent | 2 | 4 | Mouser/Rapid | https://www.mouser.com/ProductDetail/JST-Commercial/B3B-XH-ALFSN?qs=cdbOS8ANM9BVkoboCCIEMQ%3D%3D | MOQ 1 | about 1 | OK_OR_ALTERNATE | Use same pitch/orientation; Rapid showed stocked 3-pin JST if Mouser stock is poor.
Board A | J6 | 9-pin JST XH vertical UI cable header | Connector_JST:JST_XH_B9B-XH-A_1x09_P2.50mm_Vertical | JST B9B-XH-A(LF)(SN) | 1 | 2 | Mouser/search check | https://www.mouser.com/c/?q=B9B-XH-A%28LF%29%28SN%29 | MOQ 1 | about 1-2 | VERIFY_STOCK | Verify stock in cart; this must mate with Board B J1 cable housing.
Board B | J1 | 9-pin JST XH right-angle UI cable header | Connector_JST:JST_XH_S9B-XH-A_1x09_P2.50mm_Horizontal | JST S9B-XH-A(LF)(SN) | 1 | 2 | Newark/Mouser | https://www.newark.com/jst-japan-solderless-terminals/s9b-xh-a-lf-sn/wire-to-board-connector-right/dp/74M4834 | MOQ 1 | about 2-4 | OK | Newark listing showed stock; verify right-angle cable exit in 3D viewer before order.
Cables | J2,J4 mating | 2-pin JST XH cable housings | 2.5 mm JST XH housing | JST XHP-2 | 2 | 6 | Mouser/search check | https://www.mouser.com/c/?q=XHP-2%20JST | MOQ 1 | about 1 | OK | Pump and reservoir cable housings; buy extras.
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

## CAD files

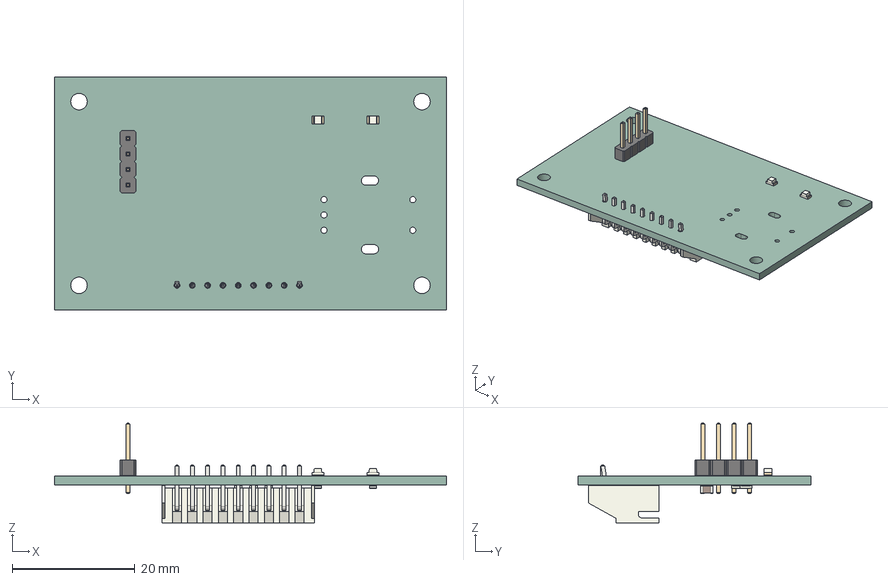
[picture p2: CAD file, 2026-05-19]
board_b_ui/mechanical/Self-Watering_UI_Board_B.step
64.0 x 38.0 x 16.3 mm
LED_0805_2012Metric x 2
PinHeader_1x04_P2.54mm_Vertical
R_0805_2012Metric x 5
C_0805_2012Metric x 3
JST_XH_S9B-XH-A_1x09_P2.50mm_Horizontal
BoardB_UI_PCB

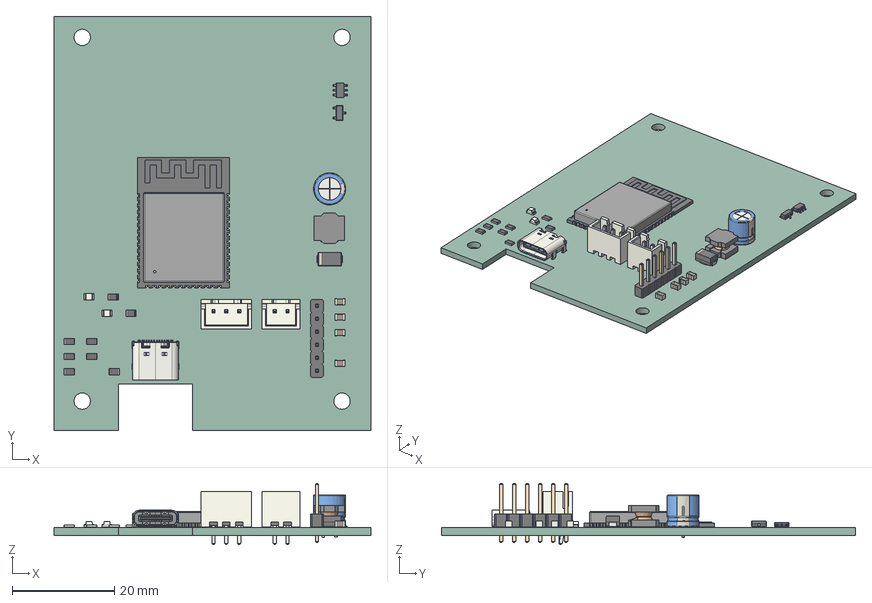
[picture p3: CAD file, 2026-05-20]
mechanical/Self-Watering_Flower_Pot_Board_A_cost_down.step
61.9 x 80.9 x 11.9 mm
R_0805_2012Metric x 8
USB_C_Receptacle_GCT_USB4105-xx-A_16P_TopMnt_Horizontal
D_SMA
LED_0805_2012Metric x 2
JST_XH_B2B-XH-A_1x02_P2.50mm_Vertical
ESP32-S3-WROOM-1
PinHeader_1x06_P2.54mm_Vertical
C_0805_2012Metric x 4
L_Bourns_SRN6045TA
TSOT-23-6
JST_XH_B3B-XH-A_1x03_P2.50mm_Vertical
SOT-23
CP_Radial_D6.3mm_P2.50mm
SmartWateringFlowerPot_PCB

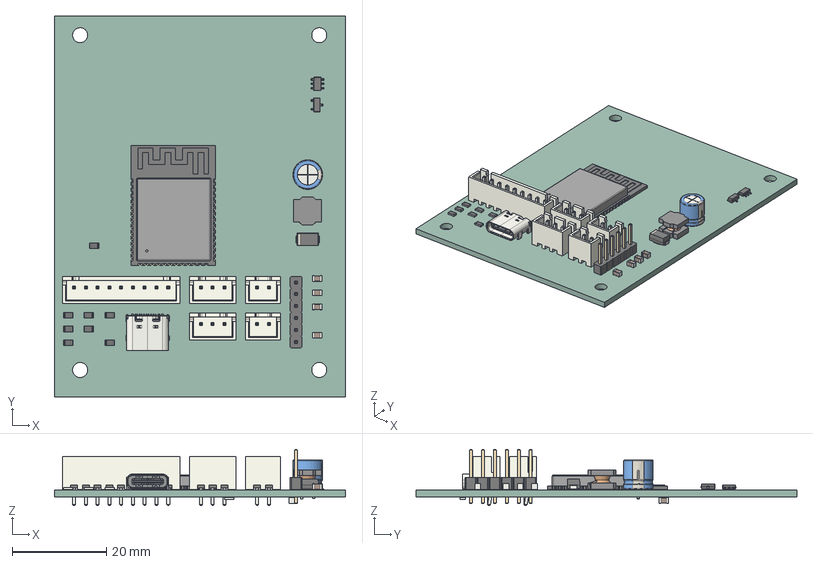
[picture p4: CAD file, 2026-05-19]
mechanical/Self-Watering_Flower_Pot_Board_A.step
61.9 x 80.9 x 11.9 mm
R_0805_2012Metric x 9
USB_C_Receptacle_GCT_USB4105-xx-A_16P_TopMnt_Horizontal
JST_XH_B2B-XH-A_1x02_P2.50mm_Vertical x 2
D_SMA
JST_XH_B3B-XH-A_1x03_P2.50mm_Vertical x 2
ESP32-S3-WROOM-1
PinHeader_1x06_P2.54mm_Vertical
C_0805_2012Metric x 5
L_Bourns_SRN6045TA
TSOT-23-6
SOT-23
JST_XH_B9B-XH-A_1x09_P2.50mm_Vertical
CP_Radial_D6.3mm_P2.50mm
SmartWateringFlowerPot_PCB

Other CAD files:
board_b_ui/mechanical/BoardB_UI.step
mechanical/BoardA.step

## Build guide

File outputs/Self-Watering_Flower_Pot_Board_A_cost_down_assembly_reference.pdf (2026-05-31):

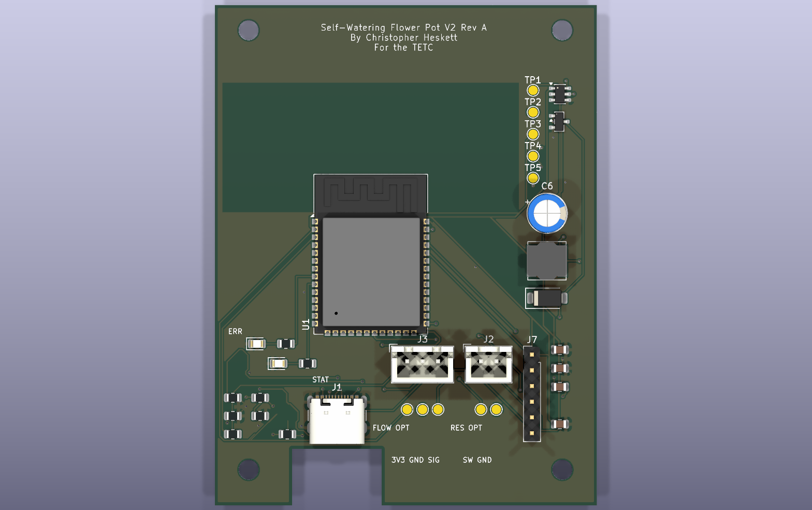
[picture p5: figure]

Generated from SmartWateringFlowerPot.kicad_pcb and board_a-cost-down-kicad-bom.csv. Not a BOM. | Page 1

# Self-Watering Flower Pot V2 - Board A Cost-Down Assembly Reference

Standalone printable placement and testpoint guide. This is intentionally separate from the BOM.

Build scope

Board A cost-down population only. Board B UI is deferred. Reservoir and flow features are exposed as optional pads, not required JST connectors.

Do not populate for minimum build

C4 optional ADC filter; older UI/reservoir/flow JST parts J4/J5/J6 and R6/R7/R8 are not part of this cost-down assembly.

First power checks

Before pump testing, measure TP1 to TP2 for +5 V and TP3 to TP2 for +3.3 V. Confirm TP4/PUMP_GATE stays low during reset/boot.

## Suggested Assembly Order

Step | Install/check | Refs
1 | USB and 3.3 V power section; verify rails before adding pump load. | J1, R1, R2, U2, L1, C1, C2, C3, C5, C6, TP1, TP2, TP3
2 | MCU and fallback programming header. | U1, R3, J7
3 | Pump driver, with pump still disconnected for first gate tests. | Q1, D1, R4, R5, J2, TP4
4 | Moisture input and local status indicators. | J3, R10, TP5, D2, D3, R11, R12
5 | Optional pad wiring only if firmware/settings enable it. | TP6, TP7, TP8, TP9, TP10

Generated from SmartWateringFlowerPot.kicad_pcb and board_a-cost-down-kicad-bom.csv. Not a BOM. | Page 2

# Component Placement: What Goes Where

All fitted parts are on the top side. Region names match the top-view image on page 1.

Ref | Part/value to place | Board area | Use / orientation note
C1 | 10uF 10V X7R input | bottom-right | Buck input capacitor; near U2/J1 power input.
C2 | 22uF 6.3V X7R output | bottom-right | Buck 3.3 V output capacitor.
C3 | 100nF 10V BST | bottom-right | AP63203 bootstrap capacitor.
C5 | 22uF 6.3V X7R output | bottom-right | Second buck 3.3 V output capacitor.
C6 | 100uF 10V pump bulk | middle-right | Pump/5 V bulk electrolytic; observe polarity.
D1 | SS34 flyback | middle-right | Pump flyback diode; use SMA B340A/SS34-class part; observe stripe orientation.
D2 | ERROR red | bottom-left | Error LED, red.
D3 | STATUS green | bottom-left | Status LED, green.
J1 | USB-C 5V + USB2 | bottom-left | USB-C 5 V input/native USB connector.
J2 | PUMP 5V | bottom-right | Pump JST-XH: pin 1 +5V/PUMP+, pin 2 PUMP_LOW/PUMP-.
J3 | MOISTURE | bottom-center | Moisture JST-XH: pin 1 +3V3, pin 2 GND, pin 3 MOISTURE_ADC.
J7 | DEBUG 3V3/GND/TX/RX/EN/BOOT | bottom-right | Fallback debug/program header: 3V3, GND, TXD0, RXD0, EN, IO0/BOOT.
Ref | Part/value to place | Board area | Use / orientation note
L1 | 3.9uH shielded >=3A Isat | middle-right | 3.9 uH buck inductor.
Q1 | AO3400A | top-right | AO3400A low-side pump MOSFET.
R1 | 5.1k CC1 | bottom-left | USB-C CC1 5.1k sink resistor.
R2 | 5.1k CC2 | bottom-left | USB-C CC2 5.1k sink resistor.
R3 | 10k EN pullup | bottom-left | ESP32 EN 10k pullup.
R4 | 220R gate | bottom-left | Pump gate series resistor.
R5 | 100k pulldown | bottom-left | Pump gate pulldown; keeps pump off at reset.
R10 | 1k ADC series | bottom-left | Moisture ADC series resistor.
R11 | 330R error LED | bottom-left | Error LED current-limit resistor.
R12 | 330R status LED | bottom-left | Status LED current-limit resistor.
U1 | ESP32-S3-WROOM-1-N8 | middle-center | ESP32-S3-WROOM-1-N8 module; antenna at top, keepout clear.
U2 | AP63203WU-7 | top-right | AP63203WU-7 3.3 V buck regulator.

## Connector Pinouts

Connector | Pins / meaning | Assembly note
J1 USB-C | VBUS=+5V, GND=GND, CC1/CC2 use R1/R2 5.1k; USB D+/D- for native ESP32 USB. | Use a real USB-C data cable for flashing.
J2 Pump | Pin 1 = +5V/PUMP+, Pin 2 = PUMP_LOW/PUMP- switched by Q1. | Do not connect pump until TP1/TP3 and TP4 behavior are verified.
J3 Moisture | Pin 1 = +3V3, Pin 2 = GND, Pin 3 = MOISTURE_ADC through R10. | Sensor output must stay at or below 3.3 V.
J7 Debug | Pin 1 = +3V3, 2 = GND, 3 = TXD0, 4 = RXD0, 5 = EN, 6 = IO0/BOOT. | Use only 3.3 V UART logic.

Generated from SmartWateringFlowerPot.kicad_pcb and board_a-cost-down-kicad-bom.csv. Not a BOM. | Page 3

# Testpoints and Optional Pads

Use TP2, TP7, or TP9 as ground reference when measuring nearby signals. Firmware defaults leave reservoir and flow sensing disabled.

TP | Net / purpose | Where on board | Expected / how to use it
TP1 | +5V rail test pad. | top-right; x=107.03 mm, y=57.98 mm | +5 V when USB/5 V supply is present.
TP2 | GND reference test pad. | top-right; x=107.03 mm, y=61.53 mm | 0 V reference ground.
TP3 | +3V3 logic rail test pad. | top-right; x=107.03 mm, y=65.08 mm | +3.3 V after AP63203 buck is working.
TP4 | PUMP_GATE test pad. | top-right; x=107.03 mm, y=68.63 mm | Normally LOW at reset/boot; about 3.3 V only when pump command is active.
TP5 | MOISTURE_ADC test pad. | middle-right; x=107.03 mm, y=72.18 mm | Analog moisture reading, 0 to 3.3 V max.
TP6 | Optional reservoir switch signal pad; firmware default disabled. | bottom-right; x=98.58 mm, y=109.63 mm | Optional switch signal; logic depends on future reservoir switch firmware setting.
TP7 | Optional ground pad for reservoir switch wiring. | bottom-right; x=101.08 mm, y=109.63 mm | 0 V reference ground.
TP8 | Optional +3V3 pad for optional sensor wiring. | bottom-center; x=86.63 mm, y=109.63 mm | +3.3 V optional sensor power pad.
TP9 | Optional ground pad for flow/optional sensor wiring. | bottom-center; x=89.13 mm, y=109.63 mm | 0 V reference ground.
TP10 | Optional flow pulse signal pad; must be 3.3 V safe if used. | bottom-center; x=91.63 mm, y=109.63 mm | Optional flow pulse input; must never exceed 3.3 V at ESP32 pin.

## Bring-Up Measurement Quick Checks

Check | Meter setup | Pass condition
No power shorts | Resistance/continuity with board unpowered | No direct short from +5V to GND or +3V3 to GND.
USB input rail | TP1 to TP2 | About +5 V.
Logic rail | TP3 to TP2 | About +3.3 V. Stop if missing before installing/testing ESP32.
Pump gate reset state | TP4 to TP2 during reset/boot | LOW/near 0 V. Pump must not turn on during reset.
Moisture input | TP5 to TP2 with sensor connected | Analog voltage between 0 and 3.3 V.

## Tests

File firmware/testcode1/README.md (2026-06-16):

# testcode1

Pump-test firmware for the Board A cost-down hardware.

This firmware is for the first controlled pump trial after the MOSFET has been installed and checked. It is not final autonomous watering firmware.

## Safety behavior

- GPIO4 `PUMP_GATE` starts LOW at boot.
- Pump control is unlocked, but every pump request is capped in firmware at `2000 ms`.
- The pump endpoint accepts only `POST` and requires a confirmation token.
- The web UI shows a first-use browser warning before running the pump button.
- The UI can request shorter pump pulses, but firmware still clamps every request to the hard `2000 ms` maximum.
- AP mode always stays enabled, even if the ESP32 joins home Wi-Fi.
- Use a dedicated 5 V supply or USB power bank for pump tests. Do not run the pump from a laptop USB port.

## Pins

| Signal | GPIO |
|---|---:|
| `MOISTURE_ADC` | 1 |
| `PUMP_GATE` | 4 |
| `RESERVOIR_SW` / `TP6` | 13 |
| `FLOW_PULSE` / `TP10` | 14 |
| `ERROR_LED` / red `D2` | 15 |
| `STATUS_LED` / green `D3` | 16 |

## Hosted UI

- AP SSID: `FlowerPot-testcode1`
- AP password: `flowerpot1`
- AP URL: `http://192.168.4.1`

The UI shows:

- pump ready/running state and remaining runtime
- adjustable manual pump pulse control with first-use warning and a 2-second firmware cap
- reset reason, boot count, previous-pump-reset clue, heap, chip temperature, loop health, and flash/sketch diagnostic cards
- home Wi-Fi settings form
- USB serial UI hints for Windows opener scripts
- moisture raw ADC value
- rolling average
- min/max/span since boot or reset
- rough moisture band: `very dry`, `dry-ish`, `moist`, or `wet`
- collapsible moisture, AP-client, and session-event charts
- flow pulse count
- pump-run, LED-test, AP-client, and export counters
- `TP6` to `TP7/GND` live short status
- `TP10` to `TP9/GND` live short status
- 5-second LED test buttons for red, green, or both LEDs
- reset-stats button for the current session counters and history
- session JSON download for firmware version, counters, moisture stats, and history points
- deep diagnostics JSON view/download

## API

- `GET /api/status`
  - Keeps the original bring-up fields: `moisture_adc_raw`, `reservoir_sw_low`, `flow_input_low`, `flow_pulses`, and `pump`.
  - Adds Wi-Fi state, pump state, moisture average/min/max/span, `moisture_band`, sample count, pump/LED counters, AP client counters, reset reason, boot count, and history metadata.
- `GET /api/diagnostics`
  - Returns the full diagnostic dump used by the hosted page.
  - Includes reset reason, persistent boot count, previous boot died-during-pump marker, heap/flash/sketch information, chip temperature, Wi-Fi state, GPIO levels, pump counters, and loop-health counters.
  - Add `?download=1` to download `flowerpot-diagnostics.json`.
  - Firmware cannot directly measure the 5 V or 3.3 V rails on this PCB; use `TP1-TP2` and `TP3-TP2` with a meter.
- `GET /api/history`
  - Returns the rolling device history buffer.
  - Current interval is about `10 s`; current capacity is `360` points, or roughly the last hour.
- `GET /api/export`
  - Downloads `flowerpot-session.json`.
  - Includes firmware identity, Wi-Fi state, counters, moisture summary, and the history buffer.
- `POST /api/pump`
  - Body must include `confirm=pump-test`.
  - Optional `duration_ms` is accepted but clamped to `2000`.
  - Returns HTTP `409` if the pump is already running.
- `POST /api/wifi`
  - Body fields: `ssid`, `password`.
  - Saves credentials in ESP32 NVS and tries to join while keeping the AP online.
- `POST /api/wifi/clear`
  - Clears saved home Wi-Fi credentials.
- `POST /api/flash?led=red|green|both`
  - Flashes the selected LED output for 5 seconds.
- `POST /api/reset-stats`
  - Resets moisture statistics, flow pulse count, pump/LED counters, AP counters, export count, and the history buffer.

## USB data-cable UI helper

The ESP32-S3 appears to Windows as a USB serial device, not as a USB network card. Firmware alone cannot force Windows to open a browser safely. This firmware prints machine-readable UI hints over USB serial instead:

- `UI_URL`
- `AP_URL`
- `STA_URL`
- AP SSID/password
- firmware version

USB serial commands:

| Command | Result |
|---|---|
| `ui` | Prints the UI URL block. |
| `status` | Prints the same JSON as `GET /api/status`. |
| `diag` | Prints the same JSON as `GET /api/diagnostics`. |
| `help` | Prints available serial commands. |

Windows helper scripts:

```powershell
.\tools\open-flowerpot-ui.ps1
```

Runs once, detects the ESP32 COM port, asks the board for its UI URL, and opens the browser.

```powershell
.\tools\watch-flowerpot-ui.ps1
```

Keeps watching for the board and opens the UI when it appears. It does not change the laptop Wi-Fi network. If the board has joined home Wi-Fi, the helper opens the home-LAN address. Otherwise it opens the AP address `http://192.168.4.1`, which still requires the browser device to be on the board AP.

## Moisture calibration notes

These bands are diagnostic only until the sensor is tested in real soil. Current observed values:

| Condition | Approx raw ADC |
|---|---:|
| Air / dry sensor | `3485-3495` |
| Loose lightly wet towel contact | `2650` |
| Pressed wet towel contact | `1900` |

For the common capacitive moisture sensor style, higher ADC readings mean drier and lower readings mean wetter.

Initial diagnostic bands in firmware:

| Band | Raw average |
|---|---:|
| `very dry` | `> 3200` |
| `dry-ish` | `2600-3200` |
| `moist` | `2000-2599` |
| `wet` | `< 2000` |

Do not use these as final watering thresholds without real soil calibration.

## First pump trial checklist

Before pressing the pump button:

- MOSFET orientation checked.
- `TP4 / PUMP_GATE` measured near `0 V` with the previous pump-disabled firmware.
- Pump flyback diode polarity checked.
- Pump connected to `J2` with correct polarity.
- Board powered from a dedicated 5 V source or USB power bank, not a laptop USB port.
- Water is kept away from the PCB.

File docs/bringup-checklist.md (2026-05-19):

# Self-Watering Flower Pot V2 Bring-Up Checklist

Use this checklist after boards arrive. Do not connect the pump until power rails, MCU behavior, and MOSFET gate behavior have been checked.

## Required Bench Setup

- Use a current-limited 5 V bench supply for first power-up if available.
- Use a dedicated 5 V, >=2 A USB adapter or USB power bank for pump operation.
- Do not run the pump while powered from a laptop USB port.
- Use a real USB-C data cable for flashing; charge-only cables will not work.
- Keep a 3.3 V USB-UART adapter available for J7 fallback programming. Never use 5 V UART logic.

## Before Soldering

- Inspect PCB for fab defects, scratches, shorts, and missing mask.
- Confirm board revision text says `Self-Watering Flower Pot V2 Rev A`.
- Confirm USB-C footprint orientation.
- Confirm ESP32 module orientation and antenna keepout.
- Confirm diode polarity markings.
- Confirm MOSFET footprint orientation against the AO3400A datasheet.
- Confirm connector labels and pin 1 markers.
- Confirm mounting holes and board outline fit the enclosure plan.

## Power Section Only

- Solder USB-C input, buck regulator, inductor, required resistors/capacitors, and rail test points first if assembly order allows.
- Do not install ESP32 until `+3V3` has been verified if practical.
- Apply current-limited 5V power.
- Measure `+5V` to `GND`.
- Measure `+3V3` to `GND`.
- Check regulator temperature.
- Check for shorts between `+5V/GND` and `+3V3/GND`.
- Confirm power LED behavior if populated.

## MCU Bring-Up

- Install ESP32-S3 module and required support parts.
- Verify ESP32 power pins receive `+3V3`.
- Verify `EN` and `BOOT` behavior.
- Check USB detection with a known data-capable USB-C cable.
- Program a minimal blink/status firmware through native USB-C first.
- If native USB flashing fails, use J7 fallback: hold `IO0/BOOT` low, pulse `EN` low, release `EN`, then upload through a 3.3 V USB-UART adapter.
- Confirm `PUMP_GATE` remains LOW during reset and boot.
- Confirm error/status LED GPIO polarity.

## Sensor and UI Tests

- Run an I2C scan and confirm OLED address.
- Display a test status page on OLED.
- Read encoder A/B transitions.
- Read encoder push button.
- Read moisture ADC in air.
- Read moisture ADC with sensor in damp soil or water only if the selected sensor supports it.
- Toggle reservoir switch and verify firmware blocks watering when empty.
- If flow sensor is installed, verify it outputs 3.3 V-safe pulses before connecting it to Board A.
- If flow sensor is installed, verify pulse counting with pump disconnected or dry-safe test setup.

## Pump Driver Tests

- Keep pump disconnected at first.
- Toggle pump GPIO and measure `PUMP_GATE`.
- Confirm gate pulldown drives MOSFET off when MCU is reset or unpowered.
- Test with a dummy load or LED/resistor if useful.
- Connect pump with current-limited 5V supply.
- Run a very short pump pulse.
- Measure pump startup and running current.
- Stop testing if pump startup causes ESP32 reset, USB dropout, or excessive voltage sag.
- Check MOSFET temperature.
- Check flyback diode orientation and temperature.
- Verify firmware max runtime stops the pump.
- Verify pump cannot turn on during reset/boot.

## Firmware Safety Checks

- Hysteresis prevents rapid pump toggling.
- Cooldown prevents repeated watering.
- Maximum runtime or maximum volume limit is enforced.
- Empty reservoir locks out pump operation.
- No-flow fault locks out pump if flow sensor is populated and no pulses arrive.
- Calibration values persist after reset.
- OLED and error LED show fault states clearly.

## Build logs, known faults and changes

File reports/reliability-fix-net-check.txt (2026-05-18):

Reliability fix readiness check
===============================
Placed components: 32
Missing placed footprints: 0
Placed-component TBD values/footprints: 0
Missing footprint refs: none
TBD refs: none

Critical net checks:
L1 value: 3.9uH shielded >=3A Isat
C5 output cap pin 1: +3V3
C6 pump bulk pin 1: +5V
C6 pump bulk pin 2: GND
TP1: +5V
TP2: GND
TP3: +3V3
TP4: Net-(Q1-G)
TP5: Net-(TP5-Pin_1)
U1 IO1: Net-(TP5-Pin_1)
Q1 gate: Net-(Q1-G)
J1 A8: unconnected-(J1-SBU1-PadA8)
J1 B8: unconnected-(J1-SBU2-PadB8)

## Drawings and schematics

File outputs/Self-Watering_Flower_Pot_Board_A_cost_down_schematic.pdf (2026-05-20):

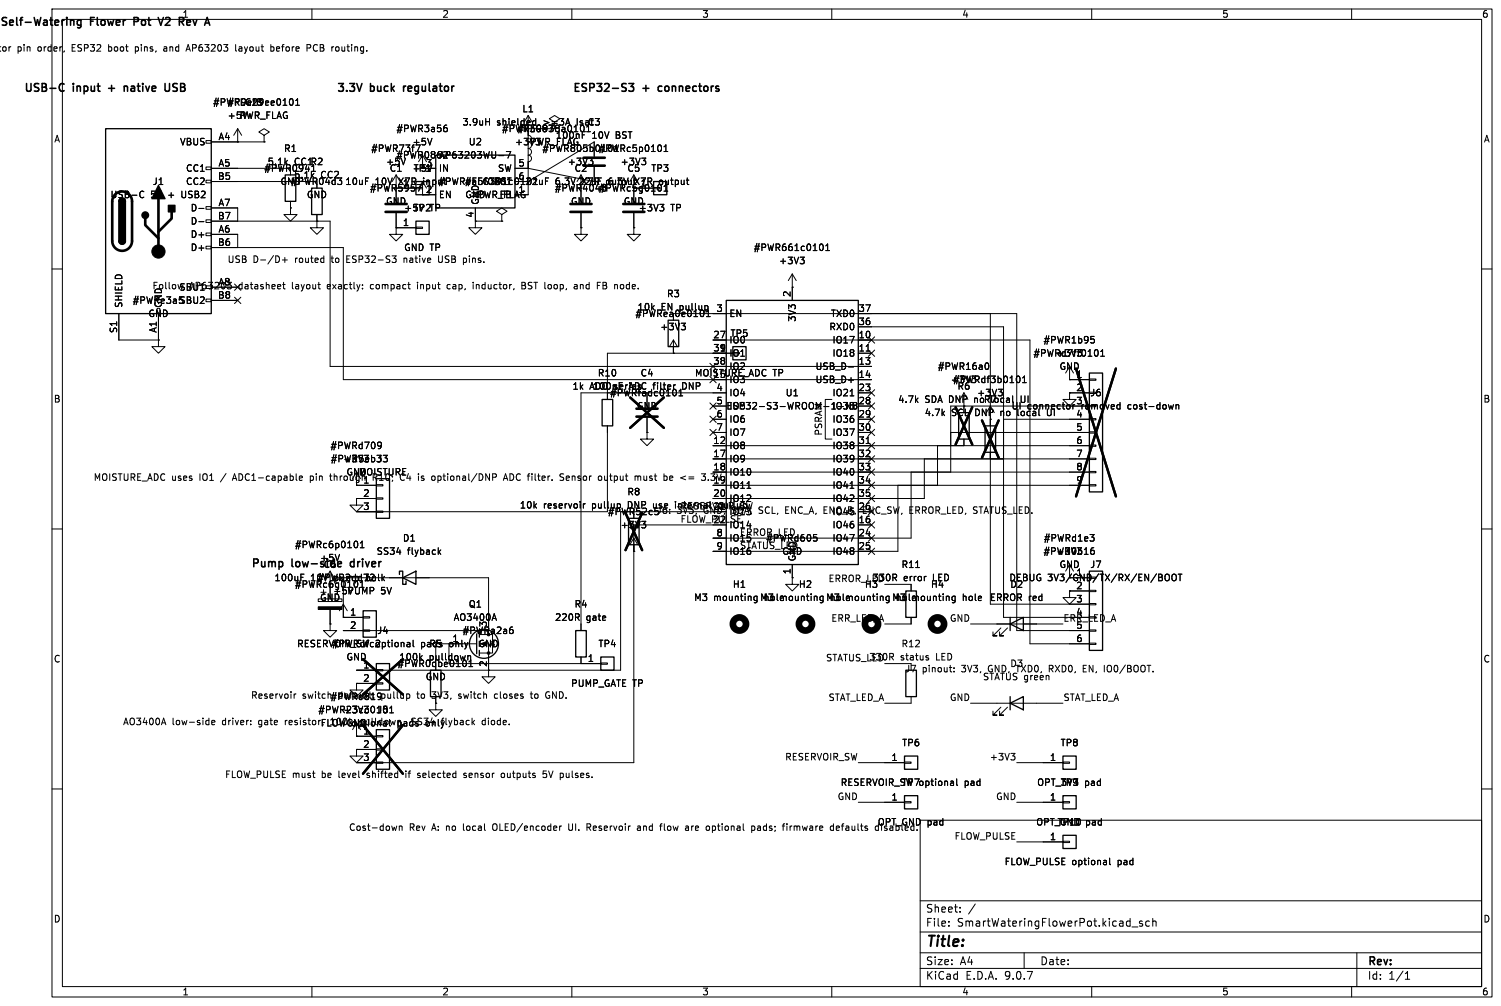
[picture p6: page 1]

#PWR16a0 +3V3 R6
#PWRdf3b0101 +3V3
J7 DEBUG 3V3/GND/TX/RX/EN/BOOT R7

4.7k SDA DNP no local UI 1

4.7k SCL DNP no local UI #PWR2dd7 +5V C6

#PWR0b16 +3V3 GND J7 DEBUG 3V3/GND/TX/RX/EN/BOOT 1

Id: 1/1 Title: File: SmartWateringFlowerPot.kicad_sch Sheet: /

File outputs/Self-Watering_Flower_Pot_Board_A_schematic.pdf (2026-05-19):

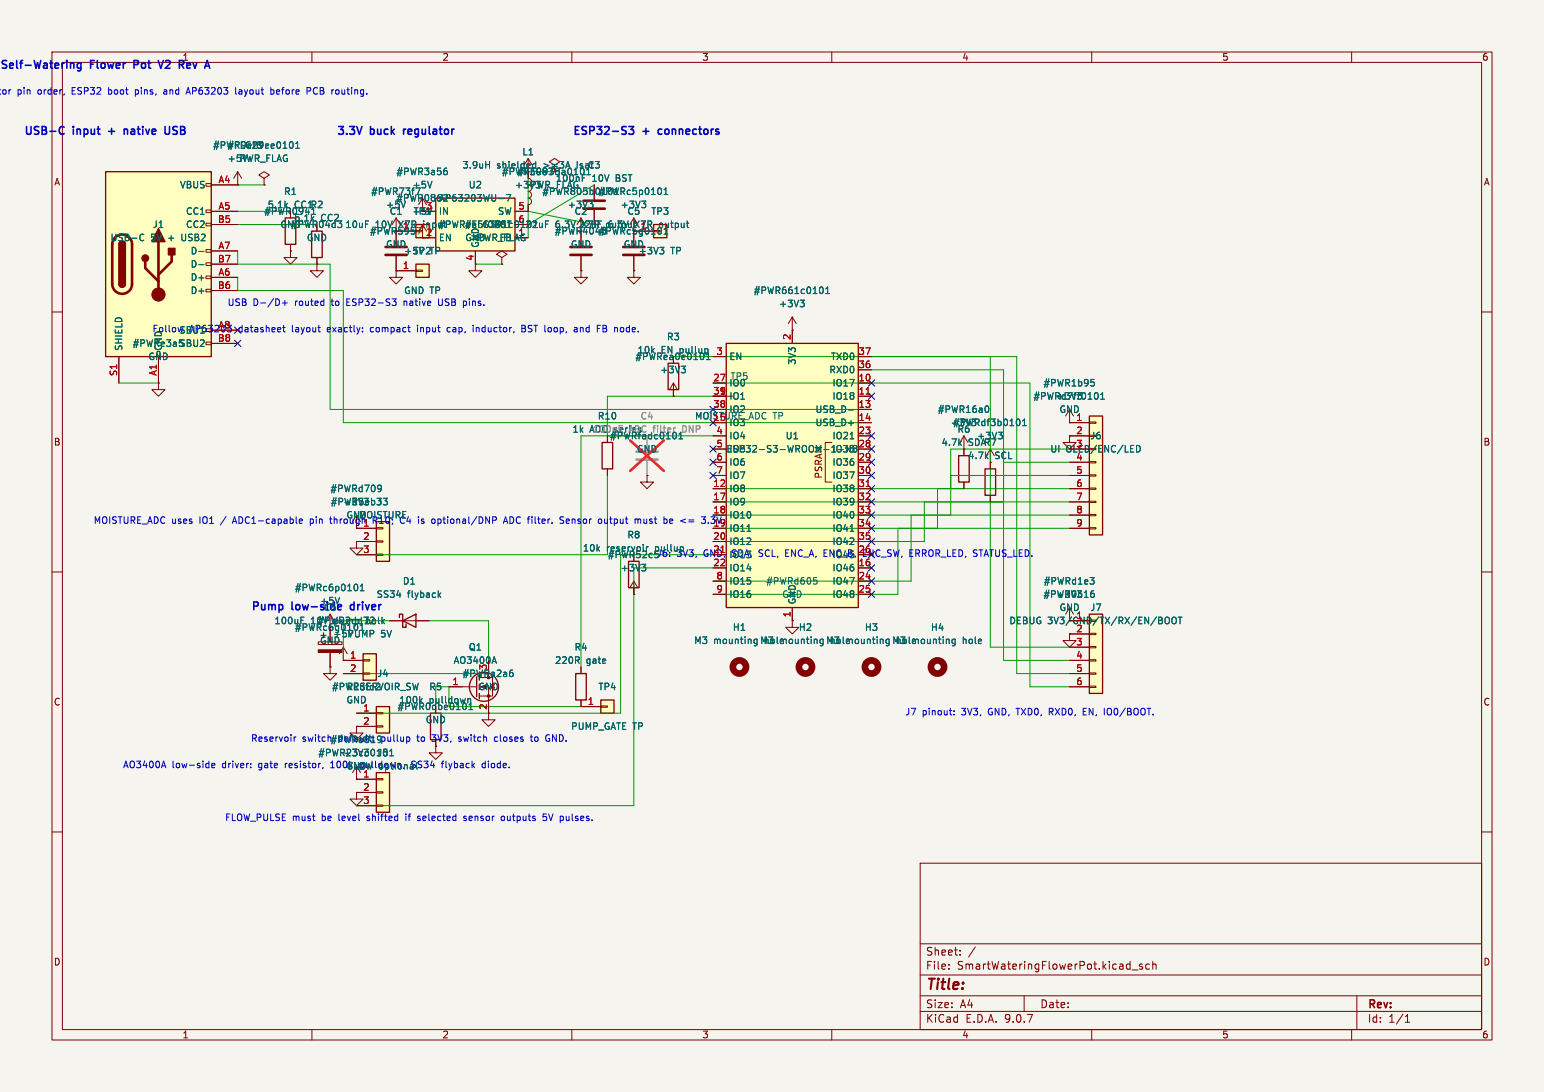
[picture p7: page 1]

100nF ADC filter DNP #PWRfadc0101 GND

J7 DEBUG 3V3/GND/TX/RX/EN/BOOT

J7 DEBUG 3V3/GND/TX/RX/EN/BOOT 1

Id: 1/1 Title: File: SmartWateringFlowerPot.kicad_sch Sheet: /

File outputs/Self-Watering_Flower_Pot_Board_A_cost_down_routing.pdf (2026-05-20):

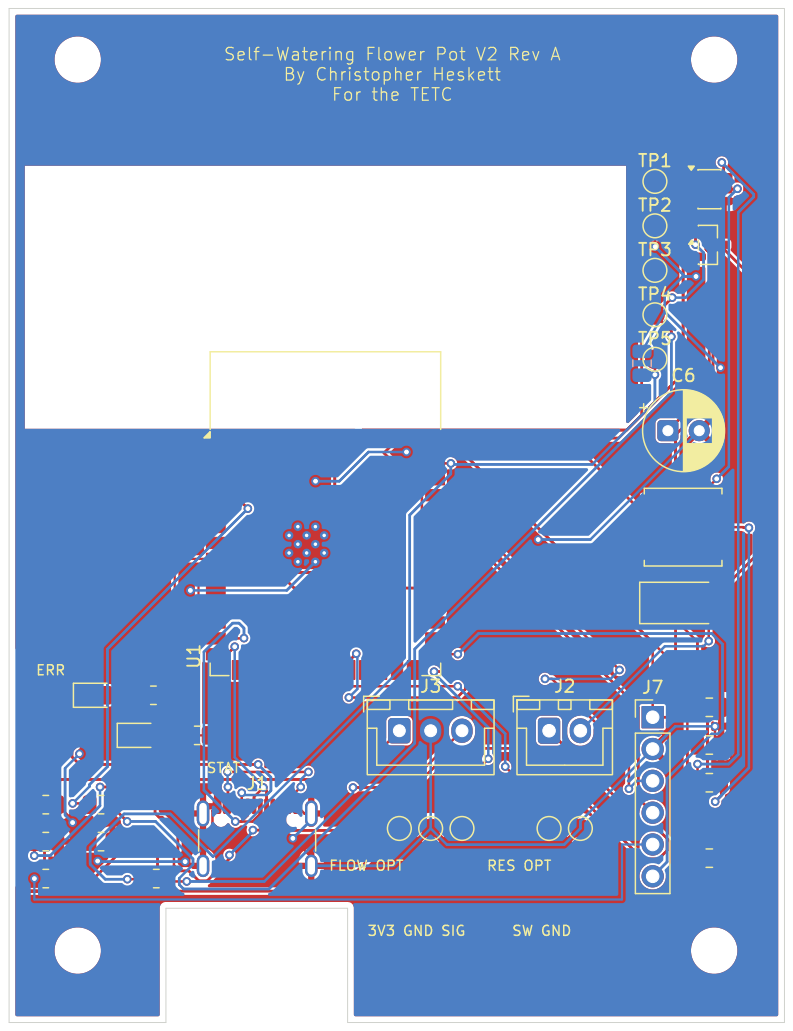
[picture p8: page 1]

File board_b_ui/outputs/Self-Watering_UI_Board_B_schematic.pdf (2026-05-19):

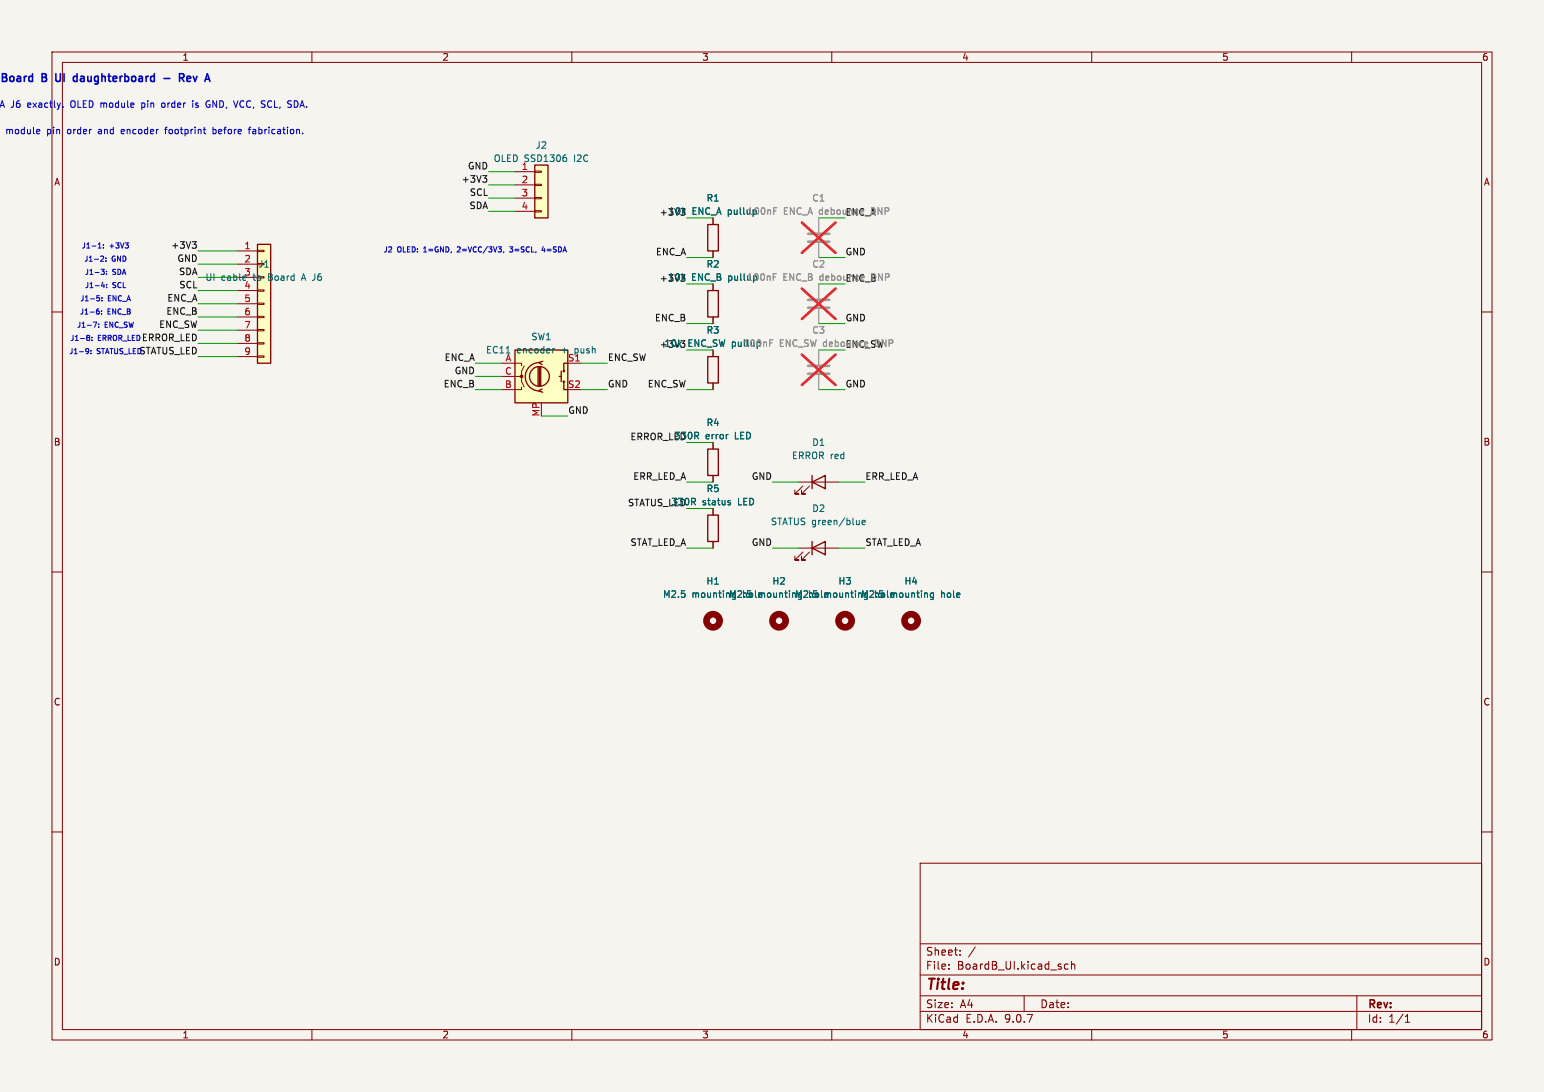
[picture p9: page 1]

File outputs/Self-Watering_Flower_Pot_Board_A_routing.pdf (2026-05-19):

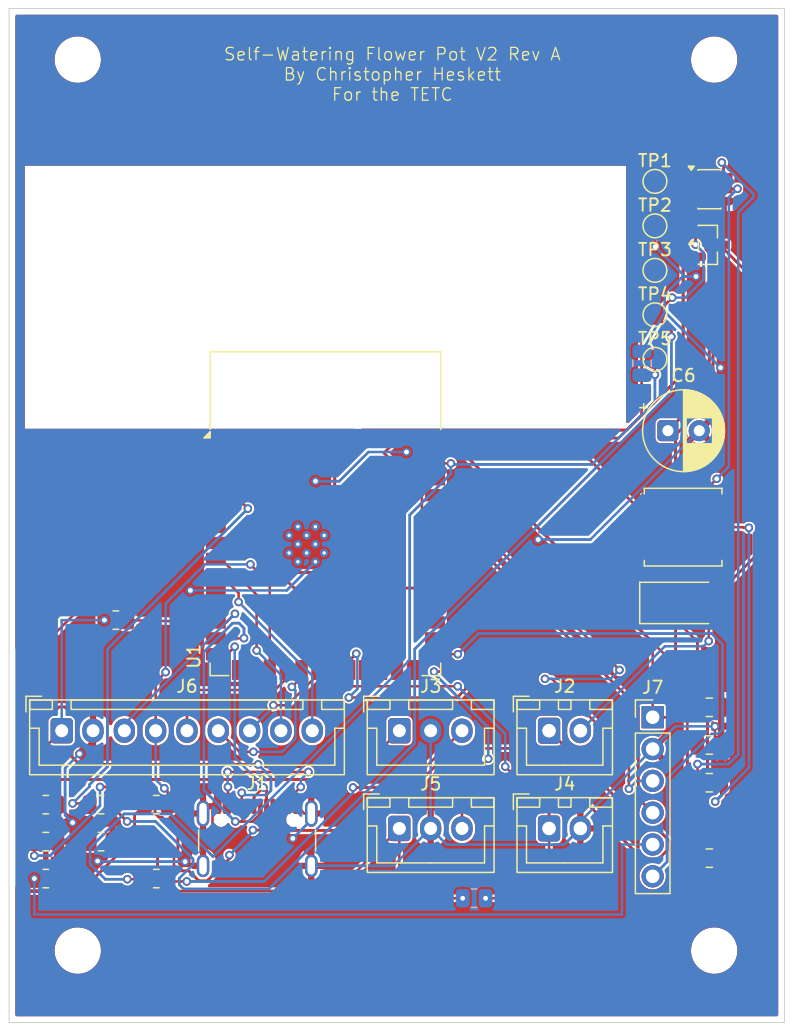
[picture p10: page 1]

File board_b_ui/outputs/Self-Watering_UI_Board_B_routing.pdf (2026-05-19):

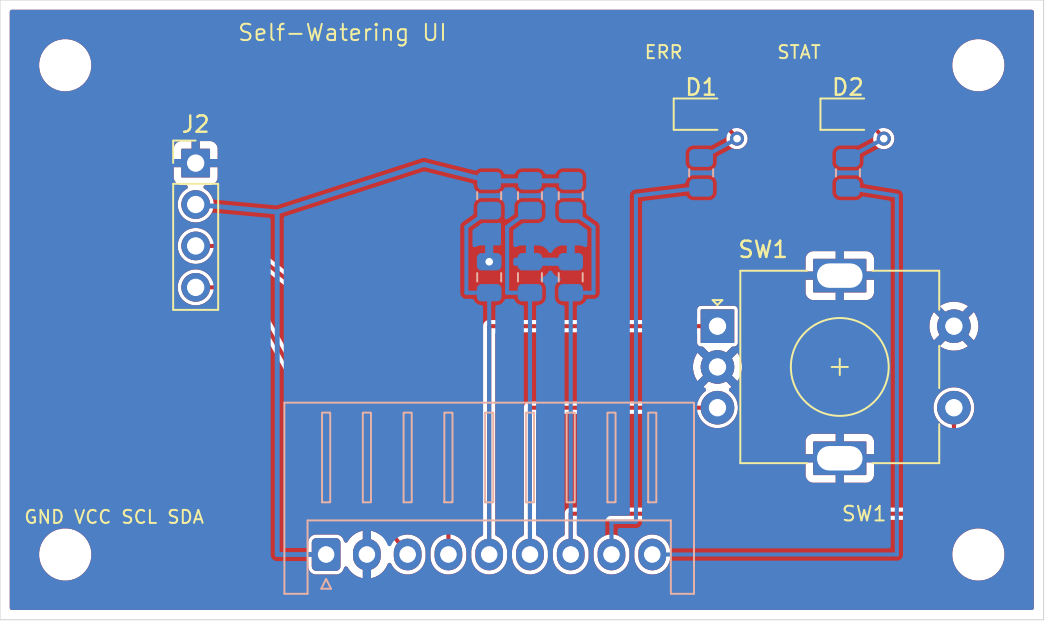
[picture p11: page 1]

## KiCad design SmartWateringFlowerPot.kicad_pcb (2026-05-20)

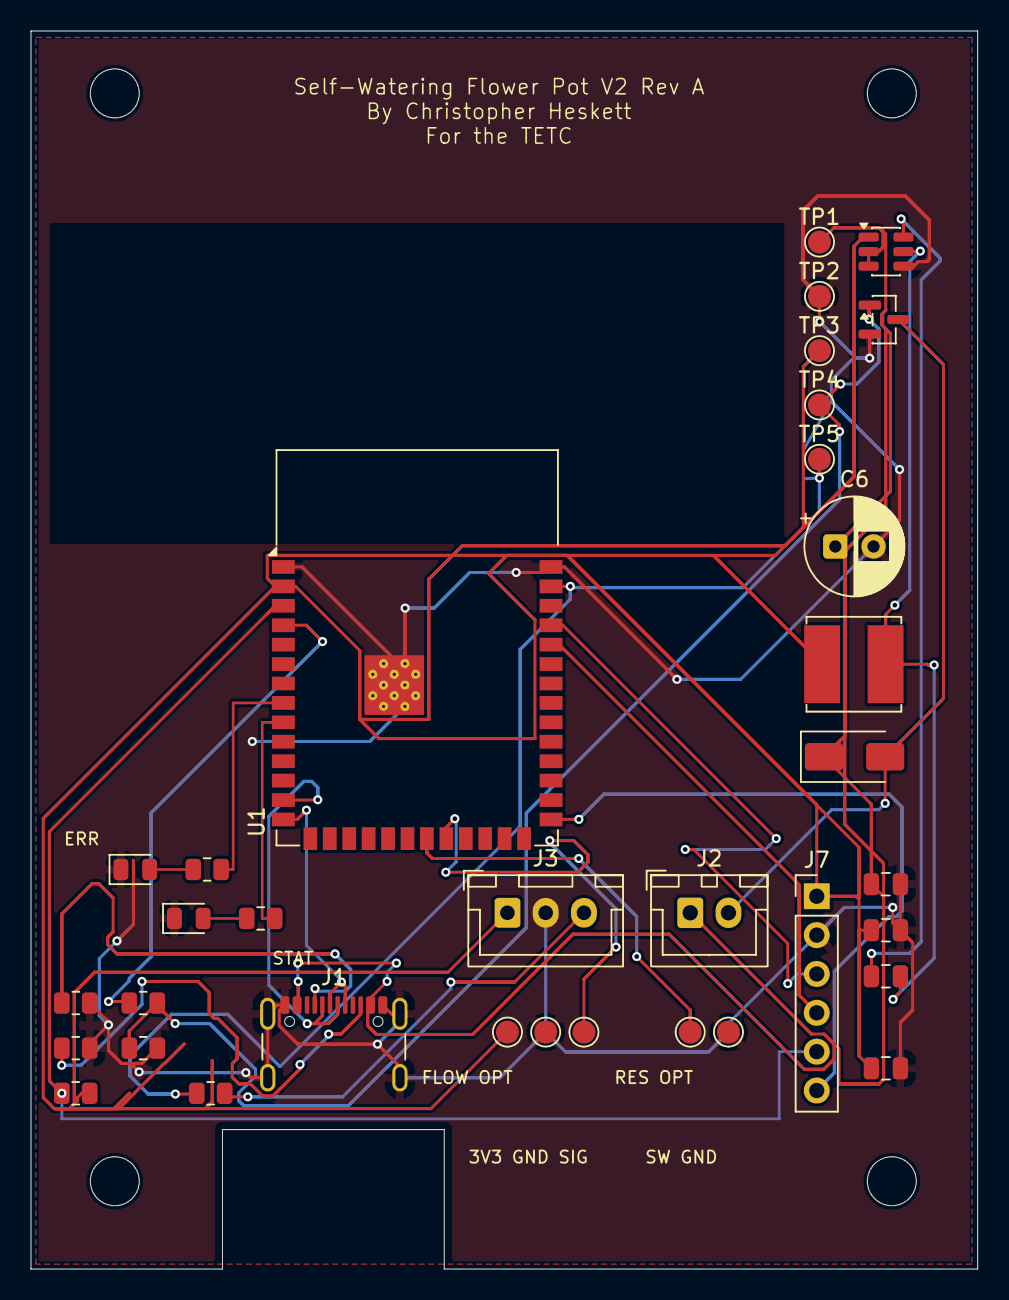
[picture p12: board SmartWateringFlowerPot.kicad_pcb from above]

Board: 2 copper layers, 61.9 x 80.9 mm, 39 parts (1 on the bottom side), 24 nets.

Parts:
C1: 10uF 10V X7R input; C_0805_2012Metric
C2, C5: 22uF 6.3V X7R output; C_0805_2012Metric
C3: 100nF 10V BST; C_0805_2012Metric
C4: 100nF ADC filter DNP; C_0805_2012Metric
C6: 100uF 10V pump bulk; CP_Radial_D6.3mm_P2.50mm
D1: SS34 flyback; D_SMA
D2: ERROR red; LED_0805_2012Metric
D3: STATUS green; LED_0805_2012Metric
H1, H2, H3, H4: M3 mounting hole; MountingHole_3.2mm_M3
J1: USB-C 5V + USB2; USB_C_Receptacle_GCT_USB4105-xx-A_16P_TopMnt_Horizontal
J2: PUMP 5V; JST_XH_B2B-XH-A_1x02_P2.50mm_Vertical
J3: MOISTURE; JST_XH_B3B-XH-A_1x03_P2.50mm_Vertical
J7: DEBUG 3V3/GND/TX/RX/EN/BOOT; PinHeader_1x06_P2.54mm_Vertical
L1: 3.9uH shielded >=3A Isat; L_Bourns_SRN6045TA
Q1: AO3400A; SOT-23
R1: 5.1k CC1; R_0805_2012Metric
R2: 5.1k CC2; R_0805_2012Metric
R3: 10k EN pullup; R_0805_2012Metric
R4: 220R gate; R_0805_2012Metric
R5: 100k pulldown; R_0805_2012Metric
R10: 1k ADC series; R_0805_2012Metric
R11: 330R error LED; R_0805_2012Metric
R12: 330R status LED; R_0805_2012Metric
TP1: +5V TP; TestPoint_Pad_D1.5mm
TP2: GND TP; TestPoint_Pad_D1.5mm
TP3: +3V3 TP; TestPoint_Pad_D1.5mm
TP4: PUMP_GATE TP; TestPoint_Pad_D1.5mm
TP5: MOISTURE_ADC TP; TestPoint_Pad_D1.5mm
TP6: RESERVOIR_SW optional pad; TestPoint_Pad_D1.5mm
TP7, TP9: OPT_GND pad; TestPoint_Pad_D1.5mm
TP8: OPT_3V3 pad; TestPoint_Pad_D1.5mm
TP10: FLOW_PULSE optional pad; TestPoint_Pad_D1.5mm
U1: ESP32-S3-WROOM-1-N8; ESP32-S3-WROOM-1
U2: AP63203WU-7; TSOT-23-6

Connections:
+3V3: C2.1, C5.1, J3.1, J7.1, L1.1, R3.2, TP3.1, TP8.1, U1.2 (3V3), U2.1 (FB)
+5V: C1.1, C6.1, D1.1 (K), J1.A4 (VBUS), J1.A9 (VBUS), J1.B4 (VBUS), J1.B9 (VBUS), J2.1, TP1.1, U2.2 (EN), U2.3 (IN)
/ERROR_LED: R11.1, U1.8 (IO15)
/ERR_LED_A: D2.2, R11.2
/FLOW_PULSE: TP10.1, U1.22 (IO14)
/RESERVOIR_SW: TP6.1, U1.21 (IO13)
/STATUS_LED: R12.1, U1.9 (IO16)
/STAT_LED_A: D3.2, R12.2
GND: C1.2, C2.2, C4.2, C5.2, C6.2, D2.1, D3.1, J1.A1 (GND), J1.A12 (GND), J1.B1 (GND), J1.B12 (GND), J1.S1 (SHIELD), J3.2, J7.2, Q1.2 (S), R1.2, R2.2, R5.2, TP2.1, TP7.1, TP9.1, U1.1 (GND), U1.40 (GND), U1.41 (GND), U2.4 (GND)
unnamed: D1.2 (A), J2.2, Q1.3 (D)
unnamed: J1.A5 (CC1), R1.1
unnamed: J1.B5 (CC2), R2.1
unnamed: J3.3, R10.2
unnamed: J7.3, U1.37 (TXD0)
unnamed: J7.4, U1.36 (RXD0)
unnamed: J7.5, R3.1, U1.3 (EN)
unnamed: J7.6, U1.27 (IO0)
unnamed: Q1.1 (G), R4.2, R5.1, TP4.1
unnamed: C4.1, R10.1, TP5.1, U1.39 (IO1)
unnamed: R4.1, U1.4 (IO4)
unnamed: J1.A6 (D+), J1.B6 (D+), U1.14 (USB_D+)
unnamed: J1.A7 (D-), J1.B7 (D-), U1.13 (USB_D-)
unnamed: C3.1, U2.6 (BST)
unnamed: C3.2, L1.2, U2.5 (SW)

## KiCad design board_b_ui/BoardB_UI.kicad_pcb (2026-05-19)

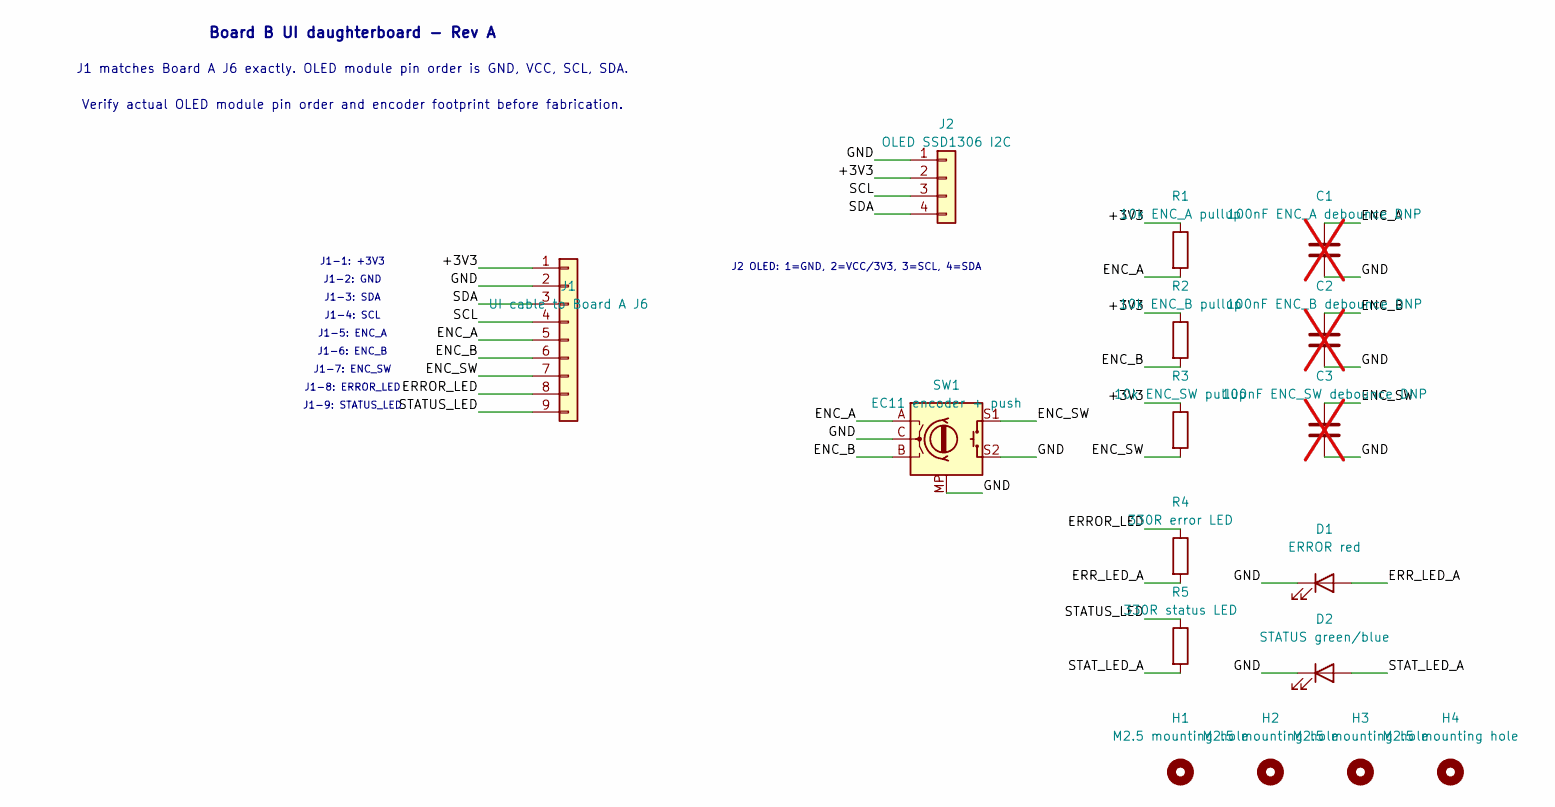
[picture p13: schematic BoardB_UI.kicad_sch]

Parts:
C1: 100nF ENC_A debounce DNP; C_0805_2012Metric; not fitted
C2: 100nF ENC_B debounce DNP; C_0805_2012Metric; not fitted
C3: 100nF ENC_SW debounce DNP; C_0805_2012Metric; not fitted
D1: ERROR red; LED_0805_2012Metric
D2: STATUS green/blue; LED_0805_2012Metric
H1, H2, H3, H4: M2.5 mounting hole; MountingHole_2.7mm_M2.5
J1: UI cable to Board A J6; JST_XH_S9B-XH-A_1x09_P2.50mm_Horizontal
J2: OLED SSD1306 I2C; PinHeader_1x04_P2.54mm_Vertical
R1: 10k ENC_A pullup; R_0805_2012Metric
R2: 10k ENC_B pullup; R_0805_2012Metric
R3: 10k ENC_SW pullup; R_0805_2012Metric
R4: 330R error LED; R_0805_2012Metric
R5: 330R status LED; R_0805_2012Metric
SW1: EC11 encoder + push; RotaryEncoder_Alps_EC11E-Switch_Vertical_H20mm

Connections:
/+3V3: J1.1, J2.2, R1.1, R2.1, R3.1
/ENC_A: C1.1, J1.5, R1.2, SW1.A
/ENC_B: C2.1, J1.6, R2.2, SW1.B
/ENC_SW: C3.1, J1.7, R3.2, SW1.S1
/ERROR_LED: J1.8, R4.1
/ERR_LED_A: D1.2 (A), R4.2
/GND: C1.2, C2.2, C3.2, D1.1 (K), D2.1 (K), J1.2, J2.1, SW1.C, SW1.MP, SW1.S2
/SCL: J1.4, J2.3
/SDA: J1.3, J2.4
/STATUS_LED: J1.9, R5.1
/STAT_LED_A: D2.2 (A), R5.2

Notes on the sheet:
Board B UI daughterboard - Rev A
J1 matches Board A J6 exactly. OLED module pin order is GND, VCC, SCL, SDA.
Verify actual OLED module pin order and encoder footprint before fabrication.
J1-1: +3V3
J1-2: GND
J1-3: SDA
J1-4: SCL
J1-5: ENC_A
J1-6: ENC_B
J1-7: ENC_SW
J1-8: ERROR_LED
J1-9: STATUS_LED
J2 OLED: 1=GND, 2=VCC/3V3, 3=SCL, 4=SDA

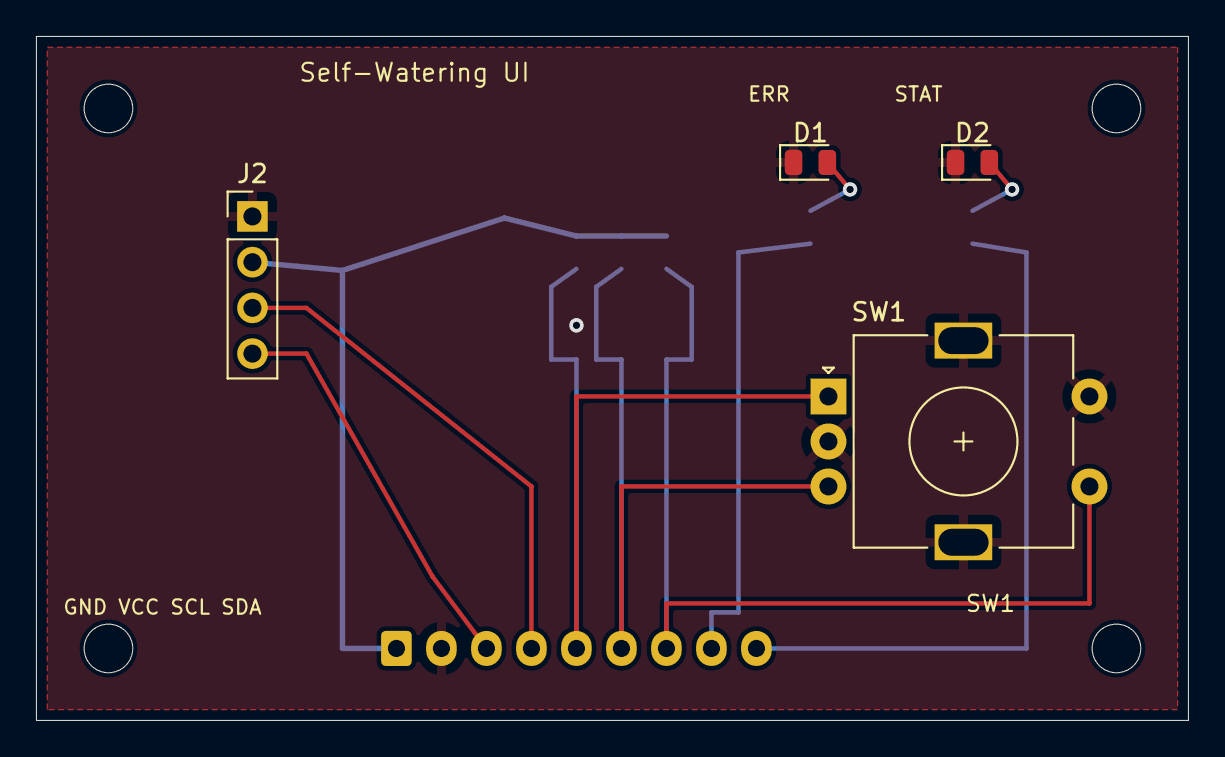
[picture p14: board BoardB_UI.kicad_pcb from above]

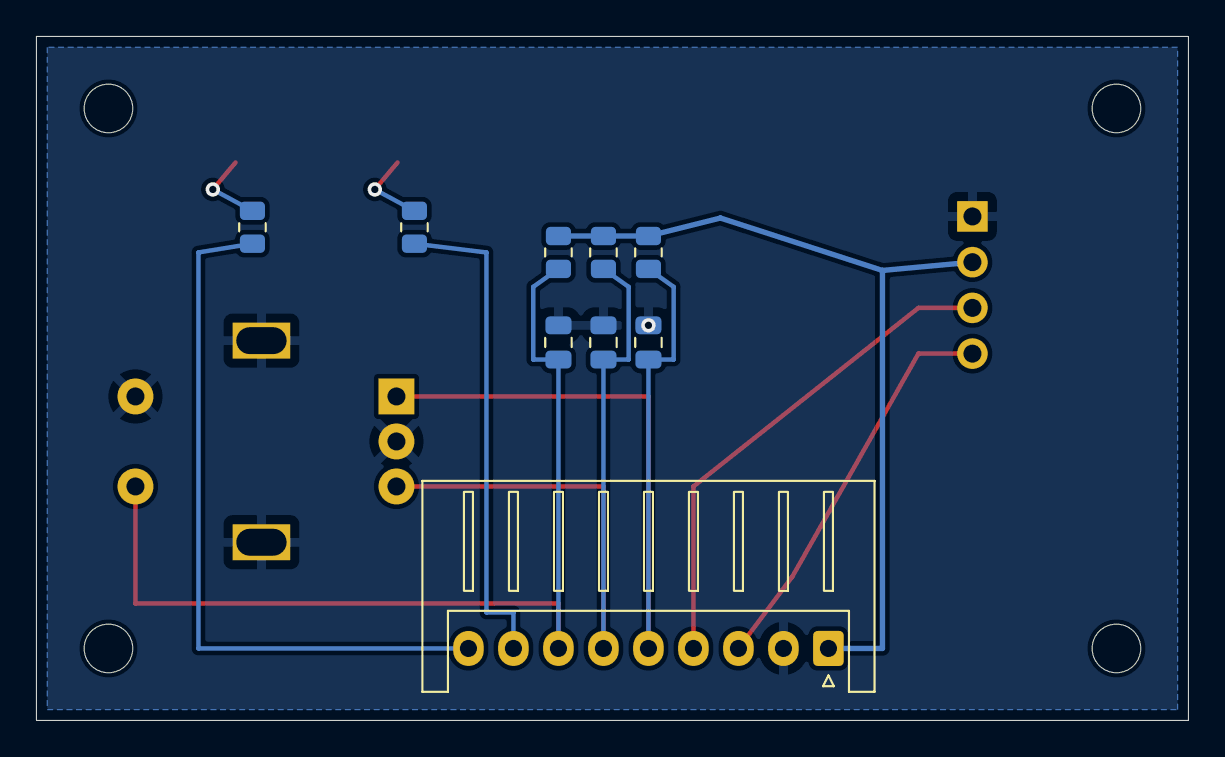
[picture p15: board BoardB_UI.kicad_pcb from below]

Board: 2 copper layers, 64.0 x 38.0 mm, 17 parts (9 on the bottom side), 11 nets.

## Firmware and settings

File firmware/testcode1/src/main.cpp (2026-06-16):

#include <Arduino.h>
#include <DNSServer.h>
#include <Preferences.h>
#include <WebServer.h>
#include <WiFi.h>
#include <esp_system.h>
#include <esp_wifi.h>

namespace {

constexpr char FIRMWARE_NAME[] = "testcode1";
constexpr char FIRMWARE_VERSION[] = "pump-diagnostics-v3";

constexpr uint8_t PIN_MOISTURE_ADC = 1;
constexpr uint8_t PIN_PUMP_GATE = 4;
constexpr uint8_t PIN_RESERVOIR_SW = 13;
constexpr uint8_t PIN_FLOW_PULSE = 14;
constexpr uint8_t PIN_ERROR_LED = 15;
constexpr uint8_t PIN_STATUS_LED = 16;

constexpr bool LED_ON = HIGH;
constexpr bool LED_OFF = LOW;
constexpr bool PUMP_OFF = LOW;
constexpr bool PUMP_ON = HIGH;

const char *AP_SSID = "FlowerPot-testcode1";
const char *AP_PASSWORD = "flowerpot1";
const IPAddress AP_IP(192, 168, 4, 1);
const IPAddress AP_GATEWAY(192, 168, 4, 1);
const IPAddress AP_SUBNET(255, 255, 255, 0);
constexpr uint16_t DNS_PORT = 53;

constexpr uint32_t MOISTURE_SAMPLE_INTERVAL_MS = 250;
constexpr uint8_t MOISTURE_AVG_WINDOW = 16;
constexpr uint16_t ADC_MAX_VALUE = 4095;

constexpr uint32_t PUMP_MAX_RUNTIME_MS = 2000;
constexpr char PUMP_CONFIRM_TOKEN[] = "pump-test";
constexpr uint32_t USB_UI_ANNOUNCE_INTERVAL_MS = 5000;
constexpr uint32_t USB_UI_FAST_ANNOUNCE_UNTIL_MS = 30000;
constexpr uint32_t HISTORY_SAMPLE_INTERVAL_MS = 10000;
constexpr uint16_t HISTORY_CAPACITY = 360;

WebServer server(80);
DNSServer dnsServer;
Preferences preferences;

String savedStaSsid = "";
String savedStaPassword = "";
uint32_t staConnectStartedMs = 0;

volatile uint32_t flowPulseCount = 0;
volatile uint32_t apConnectEvents = 0;
volatile uint32_t apDisconnectEvents = 0;

uint16_t moistureWindow[MOISTURE_AVG_WINDOW] = {};
uint8_t moistureWindowIndex = 0;
uint8_t moistureWindowCount = 0;
uint32_t moistureWindowTotal = 0;
uint32_t moistureSampleCount = 0;
uint16_t moistureRaw = 0;
uint16_t moistureMin = ADC_MAX_VALUE;
uint16_t moistureMax = 0;
uint32_t lastMoistureSampleMs = 0;

uint32_t ledTestUntilMs = 0;
String ledTestMode = "";
uint32_t reservoirLowStartedMs = 0;
uint32_t ledFlashCount = 0;
uint32_t redLedFlashCount = 0;
uint32_t greenLedFlashCount = 0;
uint32_t bothLedFlashCount = 0;

bool pumpRunning = false;
uint32_t pumpStartedMs = 0;
uint32_t pumpUntilMs = 0;
uint32_t pumpPulseCount = 0;
uint32_t pumpAttemptCount = 0;
uint32_t pumpRejectedAuthCount = 0;
uint32_t pumpRejectedBusyCount = 0;
uint32_t pumpCompletedCount = 0;
uint32_t lastPumpRequestedMs = 0;
uint32_t lastPumpActualMs = 0;
String lastPumpStopReason = "never_started";
uint32_t exportCount = 0;
uint8_t maxApClients = 0;

bool preferencesReady = false;
uint32_t bootCount = 0;
esp_reset_reason_t bootResetReason = ESP_RST_UNKNOWN;
bool previousBootPumpActive = false;
uint32_t pumpInterruptedBootCount = 0;
uint32_t previousPumpRequestedMs = 0;
uint32_t previousPumpBootCount = 0;
uint32_t loopCount = 0;
uint32_t maxLoopGapMs = 0;
uint32_t lastLoopStartedMs = 0;

struct HistoryPoint {
  uint32_t uptimeMs;
  uint16_t raw;
  uint16_t avg;
  uint8_t clients;
  bool pump;
};

HistoryPoint history[HISTORY_CAPACITY] = {};
uint16_t historyWriteIndex = 0;
uint16_t historyCount = 0;
uint32_t lastHistorySampleMs = 0;

String serialLine = "";
bool serialWasConnected = false;
uint32_t lastSerialUiAnnounceMs = 0;

String statusJson();
String historyJson();
String exportJson();
String diagnosticsJson();
void addHistoryPoint();

void IRAM_ATTR onFlowPulse() {
  flowPulseCount++;
}

void markPumpNvsActive(uint32_t requestedMs) {
  if (!preferencesReady) {
    return;
  }
  preferences.putBool("pump_active", true);
  preferences.putUInt("pump_req_ms", requestedMs);
  preferences.putUInt("pump_boot", bootCount);
}

void clearPumpNvsActive() {
  if (!preferencesReady) {
    return;
  }
  preferences.putBool("pump_active", false);
}

void setPumpOff(const String &reason = "forced_off") {
  const bool wasRunning = pumpRunning;
  const uint32_t now = millis();
  if (wasRunning) {
    lastPumpActualMs = now - pumpStartedMs;
    lastPumpStopReason = reason;
    if (reason == "runtime_elapsed") {
      pumpCompletedCount++;
    }
  }
  pumpRunning = false;
  pumpStartedMs = 0;
  pumpUntilMs = 0;
  digitalWrite(PIN_PUMP_GATE, PUMP_OFF);
  if (wasRunning) {
    clearPumpNvsActive();
    addHistoryPoint();
  }
}

void servicePumpSafety() {
  const uint32_t now = millis();
  if (pumpRunning && static_cast<int32_t>(now - pumpUntilMs) >= 0) {
    setPumpOff("runtime_elapsed");
    return;
  }
  digitalWrite(PIN_PUMP_GATE, pumpRunning ? PUMP_ON : PUMP_OFF);
}

uint32_t pumpRemainingMs() {
  if (!pumpRunning) {
    return 0;
  }
  const uint32_t now = millis();
  if (static_cast<int32_t>(pumpUntilMs - now) <= 0) {
    return 0;
  }
  return pumpUntilMs - now;
}

bool startPumpPulse(uint32_t requestedMs) {
  servicePumpSafety();
  if (pumpRunning) {
    pumpRejectedBusyCount++;
    return false;
  }
  if (requestedMs == 0 || requestedMs > PUMP_MAX_RUNTIME_MS) {
    requestedMs = PUMP_MAX_RUNTIME_MS;
  }

  const uint32_t now = millis();
  lastPumpRequestedMs = requestedMs;
  lastPumpActualMs = 0;
  lastPumpStopReason = "running";
  markPumpNvsActive(requestedMs);
  pumpRunning = true;
  pumpStartedMs = now;
  pumpUntilMs = now + requestedMs;
  pumpPulseCount++;
  digitalWrite(PIN_PUMP_GATE, PUMP_ON);
  addHistoryPoint();
  return true;
}

uint32_t readFlowPulseCount() {
  noInterrupts();
  const uint32_t count = flowPulseCount;
  interrupts();
  return count;
}

void resetFlowPulseCount() {
  noInterrupts();
  flowPulseCount = 0;
  interrupts();
}

uint32_t readApConnectEvents() {
  noInterrupts();
  const uint32_t count = apConnectEvents;
  interrupts();
  return count;
}

uint32_t readApDisconnectEvents() {
  noInterrupts();
  const uint32_t count = apDisconnectEvents;
  interrupts();
  return count;
}

uint8_t currentApClients() {
  return WiFi.softAPgetStationNum();
}

void updateMaxApClients() {
  const uint8_t clients = currentApClients();
  if (clients > maxApClients) {
    maxApClients = clients;
  }
}

void onWiFiEvent(arduino_event_id_t event) {
  if (event == ARDUINO_EVENT_WIFI_AP_STACONNECTED) {
    apConnectEvents++;
    updateMaxApClients();
  } else if (event == ARDUINO_EVENT_WIFI_AP_STADISCONNECTED) {
    apDisconnectEvents++;
    updateMaxApClients();
  }
}

String jsonEscape(const String &value) {
  String out;
  out.reserve(value.length() + 4);
  for (size_t i = 0; i < value.length(); i++) {
    const char c = value[i];
    if (c == '\\') out += F("\\\\");
    else if (c == '"') out += F("\\\"");
    else if (c == '\n') out += F("\\n");
    else if (c == '\r') out += F("\\r");
    else out += c;
  }
  return out;
}

String resetReasonName(esp_reset_reason_t reason) {
  switch (reason) {
    case ESP_RST_POWERON:
      return "power_on";
    case ESP_RST_EXT:
      return "external_reset";
    case ESP_RST_SW:
      return "software_reset";
    case ESP_RST_PANIC:
      return "panic_exception";
    case ESP_RST_INT_WDT:
      return "interrupt_watchdog";
    case ESP_RST_TASK_WDT:
      return "task_watchdog";
    case ESP_RST_WDT:
      return "other_watchdog";
    case ESP_RST_DEEPSLEEP:
      return "deep_sleep";
    case ESP_RST_BROWNOUT:
      return "brownout";
    case ESP_RST_SDIO:
      return "sdio";
    default:
      return "unknown";
  }
}

String flashModeName(FlashMode_t mode) {
  switch (mode) {
    case FM_QIO:
      return "qio";
    case FM_QOUT:
      return "qout";
    case FM_DIO:
      return "dio";
    case FM_DOUT:
      return "dout";
    default:
      return "unknown";
  }
}

float safeTemperatureC() {
  const float temp = temperatureRead();
  if (isnan(temp) || temp < -80.0f || temp > 160.0f) {
    return NAN;
  }
  return temp;
}

void resetMoistureStats() {
  moistureWindowIndex = 0;
  moistureWindowCount = 0;
  moistureWindowTotal = 0;
  moistureSampleCount = 0;
  moistureRaw = 0;
  moistureMin = ADC_MAX_VALUE;
  moistureMax = 0;
  for (uint8_t i = 0; i < MOISTURE_AVG_WINDOW; i++) {
    moistureWindow[i] = 0;
  }
}

void addMoistureSample(const uint16_t raw) {
  moistureRaw = raw;

  if (moistureWindowCount < MOISTURE_AVG_WINDOW) {
    moistureWindow[moistureWindowIndex] = raw;
    moistureWindowTotal += raw;
    moistureWindowCount++;
  } else {
    moistureWindowTotal -= moistureWindow[moistureWindowIndex];
    moistureWindow[moistureWindowIndex] = raw;
    moistureWindowTotal += raw;
  }

  moistureWindowIndex = (moistureWindowIndex + 1) % MOISTURE_AVG_WINDOW;
  moistureSampleCount++;

  if (raw < moistureMin) moistureMin = raw;
  if (raw > moistureMax) moistureMax = raw;
}

void sampleMoistureNow() {
  addMoistureSample(static_cast<uint16_t>(analogRead(PIN_MOISTURE_ADC)));
}

void updateMoistureSampler() {
  const uint32_t now = millis();
  if (now - lastMoistureSampleMs < MOISTURE_SAMPLE_INTERVAL_MS) {
    return;
  }
  lastMoistureSampleMs = now;
  sampleMoistureNow();
}

uint16_t moistureAverage() {
  if (moistureWindowCount == 0) {
    return 0;
  }
  return static_cast<uint16_t>((moistureWindowTotal + moistureWindowCount / 2) / moistureWindowCount);
}

uint16_t moistureMinValue() {
  return moistureSampleCount == 0 ? 0 : moistureMin;
}

uint16_t moistureMaxValue() {
  return moistureSampleCount == 0 ? 0 : moistureMax;
}

uint16_t moistureSpan() {
  if (moistureSampleCount == 0) {
    return 0;
  }
  return moistureMax - moistureMin;
}

void resetHistory() {
  historyWriteIndex = 0;
  historyCount = 0;
  lastHistorySampleMs = 0;
  for (uint16_t i = 0; i < HISTORY_CAPACITY; i++) {
    history[i] = {};
  }
}

void addHistoryPoint() {
  updateMaxApClients();
  history[historyWriteIndex] = {
      millis(),
      moistureRaw,
      moistureAverage(),
      currentApClients(),
      pumpRunning,
  };
  historyWriteIndex = (historyWriteIndex + 1) % HISTORY_CAPACITY;
  if (historyCount < HISTORY_CAPACITY) {
    historyCount++;
  }
}

void updateHistorySampler() {
  const uint32_t now = millis();
  if (now - lastHistorySampleMs < HISTORY_SAMPLE_INTERVAL_MS) {
    return;
  }
  lastHistorySampleMs = now;
  addHistoryPoint();
}

void appendHistoryPoints(String &json) {
  json += F("[");
  for (uint16_t i = 0; i < historyCount; i++) {
    const uint16_t index = historyCount == HISTORY_CAPACITY
                               ? (historyWriteIndex + i) % HISTORY_CAPACITY
                               : i;
    const HistoryPoint &point = history[index];
    if (i > 0) {
      json += F(",");
    }
    json += F("{\"t\":");
    json += String(point.uptimeMs);
    json += F(",\"raw\":");
    json += String(point.raw);
    json += F(",\"avg\":");
    json += String(point.avg);
    json += F(",\"clients\":");
    json += String(point.clients);
    json += F(",\"pump\":");
    json += String(point.pump ? "true" : "false");
    json += F("}");
  }
  json += F("]");
}

String moistureBand() {
  if (moistureSampleCount == 0) {
    return "starting";
  }

  const uint16_t avg = moistureAverage();
  if (avg > 3200) return "very dry";
  if (avg >= 2600) return "dry-ish";
  if (avg >= 2000) return "moist";
  return "wet";
}

String staStatusText() {
  switch (WiFi.status()) {
    case WL_CONNECTED:
      return "connected";
    case WL_NO_SSID_AVAIL:
      return "ssid_not_found";
    case WL_CONNECT_FAILED:
      return "connect_failed";
    case WL_CONNECTION_LOST:
      return "connection_lost";
    case WL_DISCONNECTED:
      return savedStaSsid.length() ? "disconnected" : "not_configured";
    case WL_IDLE_STATUS:
      return "connecting";
    default:
      return "unknown";
  }
}

String apUiUrl() {
  return "http://" + WiFi.softAPIP().toString();
}

String staUiUrl() {
  return WiFi.status() == WL_CONNECTED ? "http://" + WiFi.localIP().toString() : "";
}

String primaryUiUrl() {
  const String staUrl = staUiUrl();
  return staUrl.length() ? staUrl : apUiUrl();
}

void printUsbUiBanner() {
  const String staStatus = staStatusText();
  const String staUrl = staUiUrl();

  Serial.println();
  Serial.println("FLOWERPOT_UI_BEGIN");
  Serial.print("NAME=");
  Serial.println(FIRMWARE_NAME);
  Serial.print("VERSION=");
  Serial.println(FIRMWARE_VERSION);
  Serial.print("UI_URL=");
  Serial.println(primaryUiUrl());
  Serial.print("AP_SSID=");
  Serial.println(AP_SSID);
  Serial.print("AP_PASSWORD=");
  Serial.println(AP_PASSWORD);
  Serial.print("AP_URL=");
  Serial.println(apUiUrl());
  Serial.print("STA_CONFIGURED=");
  Serial.println(savedStaSsid.length() ? "true" : "false");
  Serial.print("STA_SSID=");
  Serial.println(savedStaSsid);
  Serial.print("STA_STATUS=");
  Serial.println(staStatus);
  Serial.print("STA_URL=");
  Serial.println(staUrl);
  Serial.print("PUMP_MAX_RUNTIME_MS=");
  Serial.println(PUMP_MAX_RUNTIME_MS);
  Serial.print("RESET_REASON=");
  Serial.println(resetReasonName(bootResetReason));
  Serial.print("BOOT_COUNT=");
  Serial.println(bootCount);
  Serial.print("PREVIOUS_BOOT_PUMP_ACTIVE=");
  Serial.println(previousBootPumpActive ? "true" : "false");
  Serial.println("COMMANDS=ui,status,diag,help");
  Serial.println("FLOWERPOT_UI_END");
}

void printSerialHelp() {
  Serial.println("FLOWERPOT_HELP_BEGIN");
  Serial.println("ui     - print browser UI URL hints");
  Serial.println("status - print /api/status JSON");
  Serial.println("diag   - print /api/diagnostics JSON");
  Serial.println("help   - print this command list");
  Serial.println("FLOWERPOT_HELP_END");
}

void handleSerialCommand(String command) {
  command.trim();
  if (command.length() == 0) {
    return;
  }

  String lower = command;
  lower.toLowerCase();

  if (lower == "ui" || lower == "url" || lower == "open") {
    printUsbUiBanner();
  } else if (lower == "status") {
    Serial.println(statusJson());
  } else if (lower == "diag" || lower == "diagnostics") {
    Serial.println(diagnosticsJson());
  } else if (lower == "help" || lower == "?") {
    printSerialHelp();
  } else {
    Serial.print("ERR unknown command: ");
    Serial.println(command);
    printSerialHelp();
  }
}

void serviceSerialUi() {
  const bool serialConnected = Serial;
  const uint32_t now = millis();

  if (serialConnected && !serialWasConnected) {
    printUsbUiBanner();
    lastSerialUiAnnounceMs = now;
  }
  serialWasConnected = serialConnected;

  if (serialConnected && now < USB_UI_FAST_ANNOUNCE_UNTIL_MS &&
      now - lastSerialUiAnnounceMs >= USB_UI_ANNOUNCE_INTERVAL_MS) {
    printUsbUiBanner();
    lastSerialUiAnnounceMs = now;
  }

  while (Serial.available() > 0) {
    const char c = static_cast<char>(Serial.read());
    if (c == '\n' || c == '\r') {
      handleSerialCommand(serialLine);
      serialLine = "";
    } else if (serialLine.length() < 96) {
      serialLine += c;
    } else {
      serialLine = "";
      Serial.println("ERR command too long");
    }
  }
}

void connectStaIfConfigured() {
  if (savedStaSsid.length() == 0) {
    return;
  }
  WiFi.begin(savedStaSsid.c_str(), savedStaPassword.c_str());
  staConnectStartedMs = millis();
}

void loadWifiSettings() {
  preferences.begin("flowerpot", false);
  preferencesReady = true;
  savedStaSsid = preferences.getString("sta_ssid", "");
  savedStaPassword = preferences.getString("sta_pass", "");
  bootCount = preferences.getUInt("boot_count", 0) + 1;
  preferences.putUInt("boot_count", bootCount);
  previousBootPumpActive = preferences.getBool("pump_active", false);
  previousPumpRequestedMs = preferences.getUInt("pump_req_ms", 0);
  previousPumpBootCount = preferences.getUInt("pump_boot", 0);
  pumpInterruptedBootCount = preferences.getUInt("pump_intr", 0);
  if (previousBootPumpActive) {
    pumpInterruptedBootCount++;
    preferences.putUInt("pump_intr", pumpInterruptedBootCount);
    preferences.putBool("pump_active", false);
  }
}

void updateStaReconnect() {
  if (savedStaSsid.length() == 0 || WiFi.status() == WL_CONNECTED) {
    return;
  }

  const uint32_t now = millis();
  if (staConnectStartedMs == 0 || now - staConnectStartedMs > 30000) {
    connectStaIfConfigured();
  }
}

String statusJson() {
  servicePumpSafety();
  const bool reservoirLow = digitalRead(PIN_RESERVOIR_SW) == LOW;
  const bool flowLow = digitalRead(PIN_FLOW_PULSE) == LOW;
  const uint32_t now = millis();
  const uint32_t flowCount = readFlowPulseCount();
  const uint8_t apClients = currentApClients();
  updateMaxApClients();
  const String band = moistureBand();
  const String staStatus = staStatusText();

  String json = "{";
  json += "\"name\":\"" + String(FIRMWARE_NAME) + "\",";
  json += "\"version\":\"" + String(FIRMWARE_VERSION) + "\",";
  json += "\"uptime_ms\":" + String(now) + ",";
  json += "\"boot_count\":" + String(bootCount) + ",";
  json += "\"reset_reason\":\"" + jsonEscape(resetReasonName(bootResetReason)) + "\",";
  json += "\"previous_boot_pump_active\":" + String(previousBootPumpActive ? "true" : "false") + ",";
  json += "\"pump_interrupted_boots\":" + String(pumpInterruptedBootCount) + ",";
  json += "\"mac\":\"" + WiFi.macAddress() + "\",";
  json += "\"ap_ssid\":\"" + String(AP_SSID) + "\",";
  json += "\"ap_ip\":\"" + WiFi.softAPIP().toString() + "\",";
  json += "\"ap_clients\":" + String(apClients) + ",";
  json += "\"clients\":" + String(apClients) + ",";
  json += "\"ap_connect_events\":" + String(readApConnectEvents()) + ",";
  json += "\"ap_disconnect_events\":" + String(readApDisconnectEvents()) + ",";
  json += "\"ap_max_clients\":" + String(maxApClients) + ",";
  json += "\"sta_configured\":" + String(savedStaSsid.length() ? "true" : "false") + ",";
  json += "\"sta_ssid\":\"" + jsonEscape(savedStaSsid) + "\",";
  json += "\"sta_status\":\"" + jsonEscape(staStatus) + "\",";
  json += "\"sta_ip\":\"" + (WiFi.status() == WL_CONNECTED ? WiFi.localIP().toString() : String("")) + "\",";
  json += "\"moisture_adc_raw\":" + String(moistureRaw) + ",";
  json += "\"moisture_adc_avg\":" + String(moistureAverage()) + ",";
  json += "\"moisture_adc_min\":" + String(moistureMinValue()) + ",";
  json += "\"moisture_adc_max\":" + String(moistureMaxValue()) + ",";
  json += "\"moisture_adc_span\":" + String(moistureSpan()) + ",";
  json += "\"moisture_band\":\"" + jsonEscape(band) + "\",";
  json += "\"samples\":" + String(moistureSampleCount) + ",";
  json += "\"reservoir_sw_low\":" + String(reservoirLow ? "true" : "false") + ",";
  json += "\"flow_input_low\":" + String(flowLow ? "true" : "false") + ",";
  json += "\"flow_pulses\":" + String(flowCount) + ",";
  json += "\"pump\":\"" + String(pumpRunning ? "running" : "ready_limited_2s") + "\",";
  json += "\"pump_running\":" + String(pumpRunning ? "true" : "false") + ",";
  json += "\"pump_remaining_ms\":" + String(pumpRemainingMs()) + ",";
  json += "\"pump_max_runtime_ms\":" + String(PUMP_MAX_RUNTIME_MS) + ",";
  json += "\"pump_pulses\":" + String(pumpPulseCount) + ",";
  json += "\"pump_attempts\":" + String(pumpAttemptCount) + ",";
  json += "\"pump_completed\":" + String(pumpCompletedCount) + ",";
  json += "\"pump_rejected_busy\":" + String(pumpRejectedBusyCount) + ",";
  json += "\"pump_rejected_auth\":" + String(pumpRejectedAuthCount) + ",";
  json += "\"last_pump_requested_ms\":" + String(lastPumpRequestedMs) + ",";
  json += "\"last_pump_actual_ms\":" + String(lastPumpActualMs) + ",";
  json += "\"last_pump_stop_reason\":\"" + jsonEscape(lastPumpStopReason) + "\",";
  json += "\"led_test\":\"" + jsonEscape(ledTestMode) + "\",";
  json += "\"led_test_remaining_ms\":" + String(ledTestUntilMs > now ? ledTestUntilMs - now : 0) + ",";
  json += "\"led_flash_count\":" + String(ledFlashCount) + ",";
  json += "\"led_flash_red\":" + String(redLedFlashCount) + ",";
  json += "\"led_flash_green\":" + String(greenLedFlashCount) + ",";
  json += "\"led_flash_both\":" + String(bothLedFlashCount) + ",";
  json += "\"history_count\":" + String(historyCount) + ",";
  json += "\"history_capacity\":" + String(HISTORY_CAPACITY) + ",";
  json += "\"history_interval_ms\":" + String(HISTORY_SAMPLE_INTERVAL_MS) + ",";
  json += "\"export_count\":" + String(exportCount);
  json += "}";
  return json;
}

String historyJson() {
  String json;
  json.reserve(256 + static_cast<uint32_t>(historyCount) * 72);
  json += F("{\"interval_ms\":");
  json += String(HISTORY_SAMPLE_INTERVAL_MS);
  json += F(",\"capacity\":");
  json += String(HISTORY_CAPACITY);
  json += F(",\"count\":");
  json += String(historyCount);
  json += F(",\"points\":");
  appendHistoryPoints(json);
  json += F("}");
  return json;
}
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
void loop() {
  const uint32_t loopStartedMs = millis();
  if (lastLoopStartedMs != 0) {
    const uint32_t gap = loopStartedMs - lastLoopStartedMs;
    if (gap > maxLoopGapMs) {
      maxLoopGapMs = gap;
    }
  }
  lastLoopStartedMs = loopStartedMs;
  loopCount++;
  servicePumpSafety();
  updateMoistureSampler();
  updateHistorySampler();
  updateStaReconnect();
  dnsServer.processNextRequest();
  server.handleClient();
  serviceSerialUi();
  updateServicePad();
  updateLeds();
  servicePumpSafety();
}

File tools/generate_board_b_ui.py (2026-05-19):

from __future__ import annotations

import json
import subprocess
import sys
import uuid
from pathlib import Path


ROOT = Path(__file__).resolve().parents[1]
BOARD_B = ROOT / "board_b_ui"
KICAD = Path(r"C:\Users\chesk\AppData\Local\Programs\KiCad\9.0")
KICAD_BIN = KICAD / "bin" / "kicad-cli.exe"
KICAD_SYMBOLS = KICAD / "share" / "kicad" / "symbols"
KICAD_FOOTPRINTS = KICAD / "share" / "kicad" / "footprints"


PROJECT_NAME = "BoardB_UI"
SHEET_UUID = "a7f04ab3-80e4-4e85-a889-5cd13073f8e9"


SIGNALS = {
    1: "+3V3",
    2: "GND",
    3: "SDA",
    4: "SCL",
    5: "ENC_A",
    6: "ENC_B",
    7: "ENC_SW",
    8: "ERROR_LED",
    9: "STATUS_LED",
}


def new_uuid() -> str:
    return str(uuid.uuid4())


def extract_symbol(library_file: Path, symbol: str, lib_id: str) -> str:
    text = library_file.read_text(encoding="utf-8")
    needle = f'(symbol "{symbol}"'
    start = text.index(needle)
    depth = 0
    in_string = False
    escaped = False
    for index, char in enumerate(text[start:], start):
        if in_string:
            if escaped:
                escaped = False
            elif char == "\\":
                escaped = True
            elif char == '"':
                in_string = False
        else:
            if char == '"':
                in_string = True
            elif char == "(":
                depth += 1
            elif char == ")":
                depth -= 1
                if depth == 0:
                    block = text[start : index + 1]
                    return block.replace(f'(symbol "{symbol}"', f'(symbol "{lib_id}"', 1)
    raise RuntimeError(f"Could not extract symbol {symbol} from {library_file}")


def symbol_libs() -> str:
    parts = [
        extract_symbol(KICAD_SYMBOLS / "Connector_Generic.kicad_sym", "Conn_01x09", "Connector_Generic:Conn_01x09"),
        extract_symbol(KICAD_SYMBOLS / "Connector_Generic.kicad_sym", "Conn_01x04", "Connector_Generic:Conn_01x04"),
        extract_symbol(KICAD_SYMBOLS / "Device.kicad_sym", "RotaryEncoder_Switch_MP", "Device:RotaryEncoder_Switch_MP"),
        extract_symbol(KICAD_SYMBOLS / "Device.kicad_sym", "R", "Device:R"),
        extract_symbol(KICAD_SYMBOLS / "Device.kicad_sym", "C", "Device:C"),
        extract_symbol(KICAD_SYMBOLS / "Device.kicad_sym", "LED", "Device:LED"),
        extract_symbol(KICAD_SYMBOLS / "Mechanical.kicad_sym", "MountingHole", "Mechanical:MountingHole"),
    ]
    return "\n".join(parts)


def wire(x1: float, y1: float, x2: float, y2: float) -> str:
    return f'''\t(wire
\t\t(pts
\t\t\t(xy {x1:.2f} {y1:.2f}) (xy {x2:.2f} {y2:.2f})
\t\t)
\t\t(stroke
\t\t\t(width 0)
\t\t\t(type default)
\t\t)
\t\t(uuid "{new_uuid()}")
\t)'''


def label(name: str, x: float, y: float, angle: int = 0, justify: str = "left bottom") -> str:
    return f'''\t(label "{name}"
\t\t(at {x:.2f} {y:.2f} {angle})
\t\t(effects
\t\t\t(font
\t\t\t\t(size 1.27 1.27)
\t\t\t)
\t\t\t(justify {justify})
\t\t)
\t\t(uuid "{new_uuid()}")
\t)'''


def text_note(text: str, x: float, y: float, size: float = 1.27, bold: bool = False) -> str:
    bold_line = "\n\t\t\t\t\t(bold yes)" if bold else ""
    return f'''\t(text "{text}"
\t\t(exclude_from_sim no)
\t\t(at {x:.2f} {y:.2f} 0)
\t\t(effects
\t\t\t(font
\t\t\t\t(size {size:.2f} {size:.2f}){bold_line}
\t\t\t)
\t\t)
\t\t(uuid "{new_uuid()}")
\t)'''


def prop(name: str, value: str, x: float, y: float, angle: int = 0, hide: bool = False) -> str:
    hide_text = " (hide yes)" if hide else ""
    return f'''\t\t(property "{name}" "{value}"
\t\t\t(at {x:.2f} {y:.2f} {angle})
\t\t\t(effects (font (size 1.27 1.27)){hide_text})
\t\t)'''


def instance(ref: str) -> str:
    return f'''\t\t(instances
\t\t\t(project ""
\t\t\t\t(path "/{SHEET_UUID}"
\t\t\t\t\t(reference "{ref}")
\t\t\t\t\t(unit 1)
\t\t\t\t)
\t\t\t)
\t\t)'''


def placed_symbol(
    lib_id: str,
    ref: str,
    value: str,
    footprint: str,
    x: float,
    y: float,
    angle: int = 0,
    pins: list[str] | None = None,
    dnp: bool = False,
    in_bom: bool = True,
) -> str:
    pins = pins or []
    pin_text = "\n".join(f'\t\t(pin "{pin}"\n\t\t\t(uuid "{new_uuid()}")\n\t\t)' for pin in pins)
    return f'''\t(symbol
\t\t(lib_id "{lib_id}")
\t\t(at {x:.2f} {y:.2f} {angle})
\t\t(unit 1)
\t\t(exclude_from_sim no)
\t\t(in_bom {"yes" if in_bom else "no"})
\t\t(on_board yes)
\t\t(dnp {"yes" if dnp else "no"})
\t\t(uuid "{new_uuid()}")
{prop("Reference", ref, x, y - 7.62, angle)}
{prop("Value", value, x, y - 5.08, angle)}
{prop("Footprint", footprint, x, y, angle, hide=True)}
{prop("Datasheet", "~", x, y, angle, hide=True)}
{pin_text}
{instance(ref)}
\t)'''


def left_stub(net: str, x: float, y: float, length: float = 5.08) -> list[str]:
    label_x = x - length
    return [wire(x, y, label_x, y), label(net, label_x, y, 180, "right bottom")]


def right_stub(net: str, x: float, y: float, length: float = 5.08) -> list[str]:
    label_x = x + length
    return [wire(x, y, label_x, y), label(net, label_x, y, 0, "left bottom")]
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

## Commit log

2026-05-18 Set up Smart Pot V2 project docs
    [SmartWateringFlowerPot.kicad_pcb, SmartWateringFlowerPot.kicad_sch]
2026-05-18 Add first schematic draft
    [SmartWateringFlowerPot.kicad_sch]
2026-05-18 Prepare schematic for PCB pass two
    [SmartWateringFlowerPot.kicad_sch, footprint-table-pass2.tsv]
2026-05-18 Improve schematic reliability for PCB readiness
    [SmartWateringFlowerPot.kicad_sch, footprint-table-pass2.tsv]
2026-05-18 Add Board B UI daughterboard
    [BoardB_UI.kicad_pcb, BoardB_UI.kicad_sch, BoardB_UI.step]
2026-05-18 Add Board B fab package and Board A hold report
    [BoardB_UI-B_Cu.gbl, BoardB_UI-B_Mask.gbs, BoardB_UI-B_Silkscreen.gbo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]
2026-05-19 Clean up Board B front panel layout
    [BoardB_UI-B_Cu.gbl, BoardB_UI-B_Mask.gbs, BoardB_UI-B_Silkscreen.gbo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]
2026-05-19 Add one-order readiness package
    [BoardB_UI-B_Cu.gbr, BoardB_UI-B_Mask.gbr, BoardB_UI-B_Paste.gbr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]
2026-05-19 Prepare clean order batch package
    [BoardA.step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]
2026-05-19 Add pre-order hardening review
    [order-readiness-purchasing-bom.csv]
2026-05-19 Rebrand order package and add five-unit BOM
    [BoardB_UI-B_Cu.gbr, BoardB_UI-B_Mask.gbr, BoardB_UI-B_Paste.gbr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]
2026-05-19 Document BOM cost reduction options
2026-05-19 Implement board-a-only cost-down redesign
    [Self-Watering_Flower_Pot_Board_A_cost_down.step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]
2026-05-20 Fix cost-down USB-C edge clearance
    [Self-Watering_Flower_Pot_Board_A_cost_down.step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]
2026-05-31 Add Board A assembly reference PDF
2026-06-06 Add labeled Board A top view
2026-06-06 Add KiCad reference designator screenshot
2026-06-06 Add Board A testcode1 firmware
2026-06-07 Add Board A presentation renders
2026-06-08 Improve safe testcode1 sensor UI
2026-06-09 Add capped pump test firmware
